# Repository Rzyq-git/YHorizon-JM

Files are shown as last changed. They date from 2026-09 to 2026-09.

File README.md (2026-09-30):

# YHorizon-JM

[中文](README.md) | [English](README.en.md)

开源关节电机。喜欢就请点个Star吧，当前仓库里的固件、SDK 和工具面向第一版样机：Classic CAN、GD32F303 驱动板。

> **本项目仅供交流学习。**
> 机械、电控、固件和 SDK 的源文件已全部公开。
> 不保证功能可靠、不保证使用安全，也不构成任何产品认证或质量承诺。
> **禁止他人将本仓库中的设计、固件、SDK 或文档用于商业用途。**
> 使用本项目造成的人身伤害、设备损坏或其它损失，由使用者自行承担。详见 [SECURITY.md](SECURITY.md)。

<p align="center">
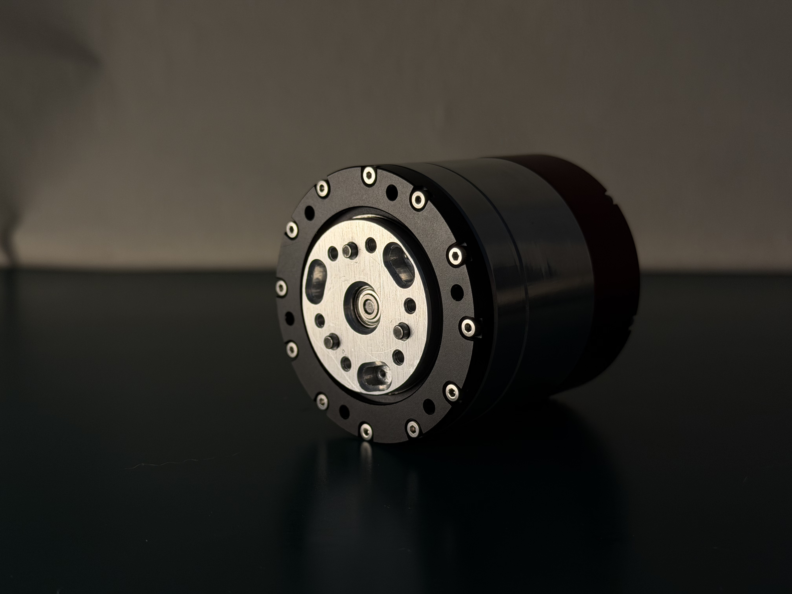
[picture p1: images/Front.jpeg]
输出法兰 / 正面
  
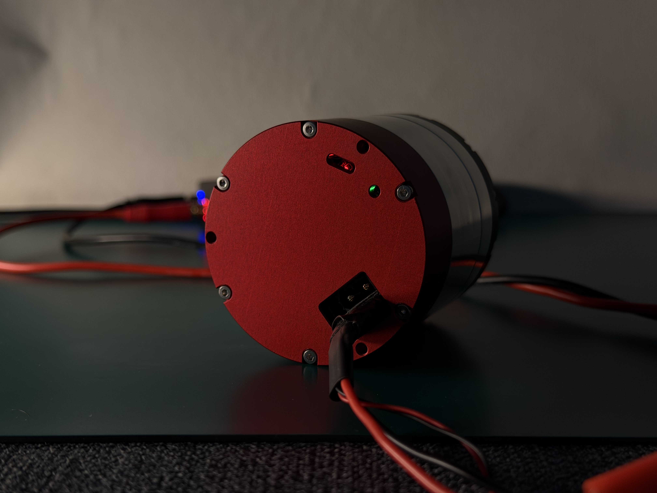
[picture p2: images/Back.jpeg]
后端盖 / 接线
  
</p>
<p align="center">
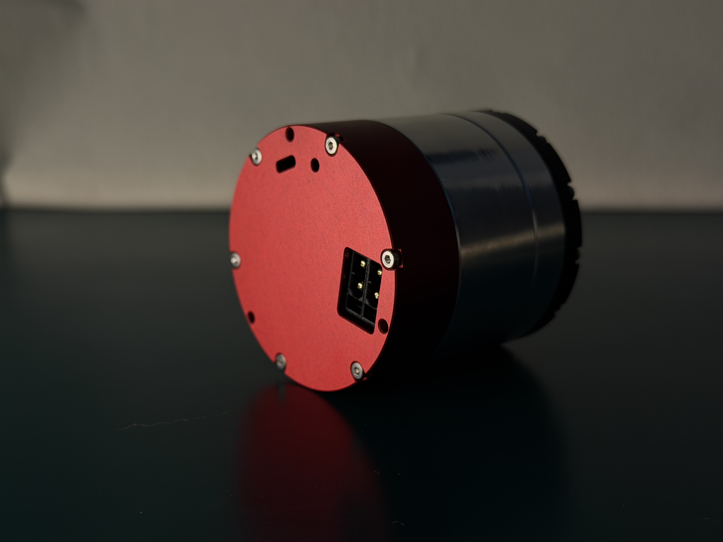
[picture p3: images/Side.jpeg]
侧面
  
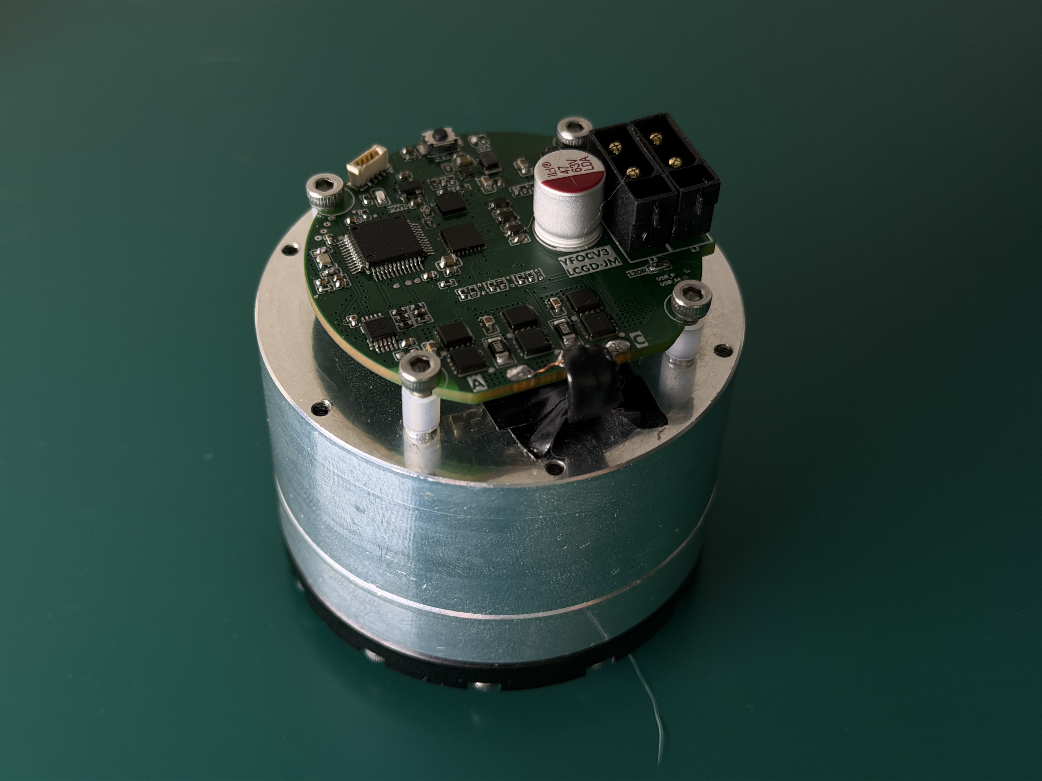
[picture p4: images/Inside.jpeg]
内部驱动板
  
</p>

<p align="center">
  正面（输出法兰）· 背面（电源与指示灯）· 侧面 · 内部驱动板
</p>

<p align="center">
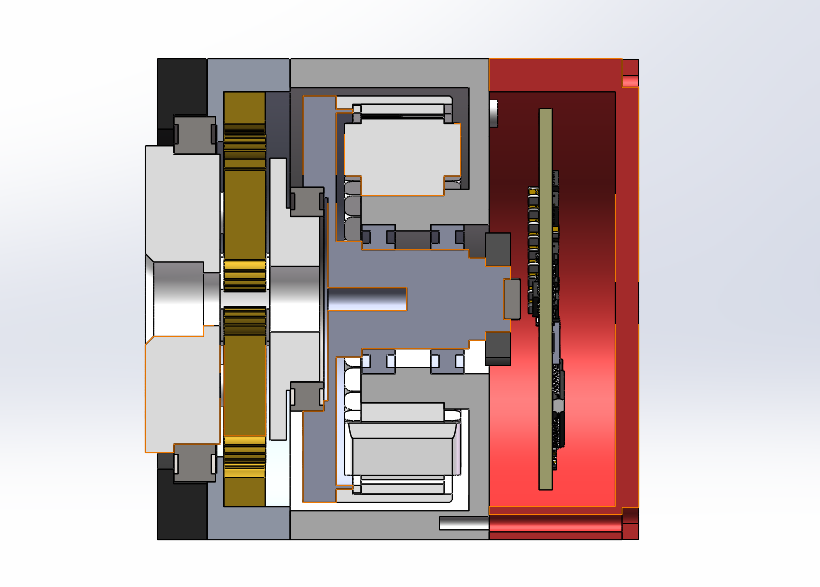
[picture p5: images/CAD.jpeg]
机械 CAD
  
</p>
<p align="center">
  机械结构（CAD）
</p>

## 当前电机

一体化关节，行星减速。第一版机械与电控：

| 项目 | 现状 |
| --- | --- |
| 外形 | 直径 57 mm，厚度 52 mm |
| 重量 | 约 300 g |
| 电机 | WK4310 参数，14 对极 |
| 减速 | 行星减速机，减速比 8 |
| 扭矩 | 额定 3 Nm，最大 6 Nm |
| 供电 | 最高 48 V |
| 编码器 | 双 MT6701 游标（30/31 齿），合成电机轴多圈后再除以减速比得到输出轴 |
| MCU | GD32F303CCT6，112 MHz |
| 功率级 | FD6288 三相驱动 |
| 总线 | Classic CAN 2.0，1 Mbps，Motor Protocol V1.0 |
| 控制 | 默认电压内环；可选电流内环。运控 / 速度 / 位置三模式 |

上电校准或加载 Flash 参数后进入运控。协议说明见 [`sdk/protocol/Motor CAN Protocol V1.0.md`](sdk/protocol/Motor%20CAN%20Protocol%20V1.0.md)（[English](sdk/protocol/Motor%20CAN%20Protocol%20V1.0.en.md)）。

测试视频：[自研关节电机阶段一完成｜D57 H52，8 倍减速，3Nm 稳定输出](https://www.bilibili.com/video/BV1CEtB6QELB/)

后续计划把主控换成 **GD32C113**，以支持 **CAN FD** 和多轴同步。机械接口与减速方案会尽量保持兼容，电控和协议会随 CAN FD 升级。

## 复刻

先对照两份清单备料、打板，不要直接下单目录里的其它文件：

- 机械零件与外购件：[`mechanical/bom/组装购买清单.xlsx`](mechanical/bom/组装购买清单.xlsx)
- 驱动器元器件：[`hardware/bom/BOM_YHorizon-JM.xlsx`](hardware/bom/BOM_YHorizon-JM.xlsx)

PCB 源工程（嘉立创 EDA Pro / EasyEDA Pro）：[`hardware/easyeda/ProPrj_YHorizon-JM.epro2`](hardware/easyeda/ProPrj_YHorizon-JM.epro2)。打板也可用 [`hardware/fabrication/Gerber_YHorizon-JM.zip`](hardware/fabrication/Gerber_YHorizon-JM.zip)，原理图 PDF 见 [`hardware/schematic/SCH_YHorizon-JM.pdf`](hardware/schematic/SCH_YHorizon-JM.pdf)。交流可加 QQ 群 **1124721315**。

装配体 STEP：[`mechanical/asm/YHorizon-JM-asm.STEP`](mechanical/asm/YHorizon-JM-asm.STEP)。CNC 零件在 `mechanical/cnc/`。**CNC 加工不保证和我们完全一致，建议多试、按自己的加工结果修改孔位。** 下单前请对照螺纹孔注意事项：

<p align="center">
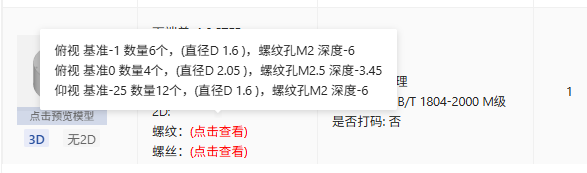
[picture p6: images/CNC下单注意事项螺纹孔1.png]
CNC 下单注意事项：螺纹孔 1
  
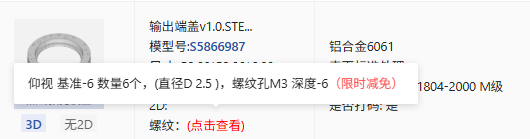
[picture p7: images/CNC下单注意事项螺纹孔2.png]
CNC 下单注意事项：螺纹孔 2
  
</p>
<p align="center">
  CNC 下单注意事项：螺纹孔 3
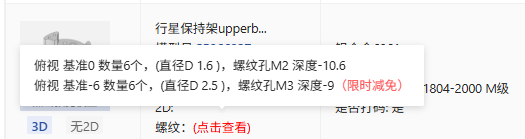
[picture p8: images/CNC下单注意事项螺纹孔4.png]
CNC 下单注意事项：螺纹孔 4
  
</p>
<p align="center">
  CNC 下单注意事项（螺纹孔）
</p>

也可以买一份我们整理的多余零部件套件，省去自己打板和配齿轮、螺丝：成品驱动板、减速机齿轮和部分螺丝等。预售在闲鱼（口令 **CZ225**）：[套件链接](https://m.tb.cn/h.8FFGGjp?tk=cgNcTkelna0)。

清单之外需要自己准备的工具（不限于）：

- 压力机
- 乐泰（Loctite）螺纹胶 / 固持胶
- 内六角扳手、小十字螺丝刀
- 烧录器线：0.8 mm 刺破式端子线

装配过程请看下面的视频：

- 测试：[自研关节电机阶段一完成｜D57 H52，8 倍减速，3Nm 稳定输出](https://www.bilibili.com/video/BV1CEtB6QELB/)
- 总装：[抖音装配视频](https://v.douyin.com/Lvc5RXRxO6M/)

复刻仅供交流学习，禁止商用。装配和上电前请阅读 [SECURITY.md](SECURITY.md)。

## 仓库结构

| 目录 | 内容 |
| --- | --- |
| `mechanical/asm/` | 装配体 STEP |
| `mechanical/cnc/` | CNC 模型 |
| `mechanical/gears/` | 齿轮 |
| `mechanical/bom/` | 零件 BOM |
| `hardware/easyeda/` | 嘉立创 EDA Pro 源工程 |
| `hardware/schematic/` | 原理图 |
| `hardware/fabrication/` | 制板文件 |
| `hardware/bom/` | 元器件 BOM |
| `firmware/` | GD32F303 固件 |
| `sdk/python/` | 上位机 Python SDK / GUI |
| `sdk/protocol/` | CAN 协议 |
| `tools/` | 环境、编译、烧录脚本 |
| `images/` | 样机照片、CAD 与 CNC 下单注意事项 |

## 固件

需要 `arm-none-eabi-gcc` 与 CMake + Ninja。产物：`firmware/build/gd32f303/YHorizon-JM.elf`。CLion 打开 `firmware/`，选择 preset `gd32f303`。

Windows：

```powershell
.\tools\setup-env.ps1
.\tools\build.ps1
.\tools\flash.ps1
```

Ubuntu：

```bash
./tools/setup-env.sh
./tools/build.sh
./tools/flash.sh
./tools/run-gui.sh
```

`setup-env.sh` 缺什么就用 apt 装什么，并创建 `sdk/python/.venv`。烧录探针为 CMSIS-DAP + SWD。发行版 OpenOCD 一般没有 `gd32f30x` 驱动，脚本会改用 `tools/openocd-gd32f303-stm32f1x.cfg`（按 256 KB，且不做 `mass_erase`）。

## 上位机

Ubuntu 跑完 `./tools/setup-env.sh` 后可直接 `./tools/run-gui.sh`。也可手动：

```bash
cd sdk/python
python3 -m venv .venv
source .venv/bin/activate   # Windows: .venv\Scripts\Activate.ps1
pip install -r requirements.txt
python servo_gui.py
```

CLI 示例：`python servo_host.py --interface socketcan --channel can0 --id 1 --listen`。协议说明见 `sdk/protocol/`。

## 许可证

采用双重许可证，详见 [`LICENSE`](LICENSE)。**源文件已全部公开；无论选用哪套许可证，本项目均仅供交流学习，禁止他人商用。**

| 内容 | 许可证 | 要点 |
| --- | --- | --- |
| `mechanical/`、`hardware/` | [CC BY-NC-SA 4.0](LICENSES/CC-BY-NC-SA-4.0.txt) | 禁止商用；衍生作品需同样开源并署名 |
| `firmware/`、`sdk/`、`tools/` | [GPLv3](LICENSES/GPL-3.0.txt) | 可学习、修改和分发；衍生软件必须继续按 GPLv3 开源 |

## 安全

完整免责声明见 [SECURITY.md](SECURITY.md)。关节电机能输出较大力矩；未完成限位、过流和急停验证前，不要在人体附近满功率运行。

## 贡献

见 [CONTRIBUTING.md](CONTRIBUTING.md)。

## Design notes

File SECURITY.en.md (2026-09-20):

# Disclaimer and safety

[中文](SECURITY.md) | [English](SECURITY.en.md)

Mechanical designs, electronics, firmware, SDK, tools, and documentation in this repository (the "Project") are provided for study and technical exchange only. Publishing this material does not mean the authors or contributors offer a product, support, training, or any warranty.

## Disclaimer

- The Project is provided "as is". It is not warranted for any particular purpose, continuous operation, freedom from defects, or compliance with functional safety, electrical safety, or other regulations.
- A joint motor can produce enough torque in a short time to crush a hand, throw a fixture, or damage a gearbox. Wrong wiring, wrong parameters, missing calibration, or failed protection can cause personal injury and property damage.
- Anyone who machines, assembles, flashes, tests, modifies, or integrates the Project does so at their own risk. Authors and contributors are not liable for direct, indirect, incidental, or consequential damages, including but not limited to personal injury, equipment damage, data loss, downtime, and commercial loss.
- The Project is not a certified industrial product. Before using it in a humanoid, cobot, near-person setting, vehicle, or any system that could cause harm, the user must complete their own risk assessment, testing, and safety measures.
- **Commercial use of the Project is prohibited.** Production, sale, paid integration, or other use for profit is outside the authors' authorization. Study, experiment, and open-source collaboration are the intended uses.

Using, copying, modifying, or distributing the Project means you have read and accepted these terms. Full licenses: [`LICENSE`](LICENSE).

## Before use

- Confirm mechanical limits, coupling/flange screws, and cable strain relief.
- Provide a hardware e-stop. Do not rely on a software stop alone.
- Jog first at low bus voltage and low current limits.
- Do not enable the position loop or high-gain impedance/force control before encoder calibration.
- Do not run at full power until current, temperature, and position limits have been verified.

## During operation

- Keep people, cables, and fixtures outside the output-flange envelope.
- Watch driver temperature, bus voltage, and fault codes.
- Power off immediately on runaway, abnormal noise, encoder jumps, or signs of over-current.
- Do not connect an uncalibrated torque loop to a humanoid or cobot load.

## Reporting safety issues

Treat firmware bugs, hardware design errors, and protection failures as safety issues. Do not post reproduction steps in a public Issue if they can directly cause over-current, runaway, or uncontrolled torque.

Report privately to maintainers when possible, including:

- Affected module (mechanical / hardware / firmware / SDK)
- Symptom and potential harm
- Software or hardware version
- Mitigations already applied

Maintainers may fix the issue or add documentation. That does not change this disclaimer: the Project still does not promise timely fixes and does not accept liability for use.

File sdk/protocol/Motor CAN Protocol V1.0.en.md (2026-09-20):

# Motor CAN Protocol V1.0

[中文](Motor%20CAN%20Protocol%20V1.0.md) | [English](Motor%20CAN%20Protocol%20V1.0.en.md)

Protocol actually implemented by current YHorizon-JM firmware. Classic CAN 2.0, 11-bit ID, DLC = 8, 1 Mbps, little-endian. Motor ID = 1~63. Position and velocity are on the **output shaft** (motor shaft / gear ratio 8).

After power-on calibration or a successful Flash load the drive enters `RUNNING`. There is no `ENABLE` / `DISABLE`. Voltage inner loop by default; `CFG_INNER_LOOP` in `config.h` can select current inner loop. CAN still encodes `t_ref` in voltage units.

## CAN IDs

| CAN ID | Direction | Function |
| --- | --- | --- |
| `0x100 + ID` | Host → motor | Motion command |
| `0x140 + ID` | Host → motor | Velocity command |
| `0x180 + ID` | Host → motor | SET gains |
| `0x180 + ID` | Motor → host | GET gains reply |
| `0x1C0 + ID` | Host → motor | Position command |
| `0x200 + ID` | Host → motor | Management |
| `0x280 + ID` | Motor → host | Command ACK |
| `0x300 + ID` | Motor → host | Motion feedback |
| `0x380 + ID` | Motor → host | GET_STATUS reply |
| `0x3C0 + ID` | Motor → host | Calibration progress |

## Control mode and state

```text
Control Mode    0x00 MOTION    0x01 VELOCITY    0x02 POSITION
Motor State     0x02 RUNNING   0x03 FAULT       0x04 CALIBRATING
```

Power-on default is `MOTION`. `SET_CONTROL_MODE` may switch while `RUNNING`; integrators are cleared and voltage is 0 until a valid real-time command for the new mode arrives. The drive executes only real-time frames that match the current mode; others are dropped with no feedback.

If several real-time frames arrive in one RX pass, only the last valid one is applied. There is no timeout: the last frame is held until a new command of the same mode, a mode change, calibration, FAULT, or power-off. To stop, send zero speed / current position, or power down.

Calibration blocks the main loop for several seconds. Other commands are not handled during that time; queued motion frames are discarded afterward.

## Real-time commands

Call `SET_CONTROL_MODE` first, then send matching real-time frames. A valid frame is answered with `0x300` and no extra ACK.

### Motion `0x100 + ID`

| Byte | Field | Type | Encoding |
| --- | --- | --- | --- |
| 0~3 | Position command | `int32` | `0.0001 rad/LSB` |
| 4~5 | Velocity command | `int16` | `0.1 rad/s/LSB`; values beyond about `±3276.7` are clamped, then still executed |
| 6~7 | Voltage FF | `int16` | `raw / 32767` → −1~1 |

```text
t_ref = Kd*(v_set - v_act) + Kp*(p_set - p_act) + Voltage_ff
t_ref = clamp(t_ref, ±V_LIMIT)
```

`V_LIMIT` defaults to 0.50 pu (1.0 = full PWM).

### Velocity `0x140 + ID`

| Byte | Field | Type | Encoding |
| --- | --- | --- | --- |
| 0~3 | Velocity command | `int32` | `0.1 rad/s/LSB` |
| 4~7 | Reserved | | Must be 0, otherwise the frame is dropped |

```text
u = Kp*e_v + Ki*∫e_v dt     integral clamped to ±V_LIMIT
```

### Position `0x1C0 + ID`

| Byte | Field | Type | Encoding |
| --- | --- | --- | --- |
| 0~3 | Position command | `int32` | `0.0001 rad/LSB` |
| 4~7 | Maximum velocity | `uint32` | `0.1 rad/s/LSB`, absolute limit |

A position PID outer loop builds `v_ref` (clamped to `±vmax`), then the velocity PI inner loop runs with the VELOCITY gain set. Outer-loop integration freezes while the inner loop is saturated.

### Motion feedback `0x300 + ID`

| Byte | Field | Type | Encoding |
| --- | --- | --- | --- |
| 0~3 | Position | `int32` | `0.0001 rad/LSB`, continuous multi-turn |
| 4~5 | Velocity | `int16` | `0.1 rad/s/LSB` |
| 6~7 | Voltage command | `int16` | `0.001 pu/LSB` (protocol torque field; no torque sensor) |

Reported only after a valid real-time command.

## Gains `0x180 + ID`

SET: host → motor. Successful GET: motor → host, same layout.

| Byte | Field |
| --- | --- |
| 0 | Control Mode |
| 1 | Sequence |
| 2~3 | Kp `uint16` |
| 4~5 | Ki `uint16` |
| 6~7 | Kd `uint16` |

| Mode | Kp | Ki | Kd |
| --- | --- | --- | --- |
| MOTION | `0.01 pu/rad` | Must be 0 | `0.001 pu·s/rad` |
| VELOCITY | `0.001 pu/(rad/s)` | `0.001 pu/rad` | Must be 0 |
| POSITION | `0.01 s⁻¹` | `0.001 s⁻²` | `0.001` |

SET updates RAM only. ACK is on `0x280` (Command=`0x20`). Illegal mode, or a gain that must be 0 is not 0 → `PARAMETER_OUT_OF_RANGE`, previous parameters kept. Motion gains are not stored across power cycles; velocity/position gains are written to Flash with `SAVE_USER_PARAMS`.

GET_GAINS (`0x200`, Byte0=`0x21`, Byte2=mode, rest 0): success returns current RAM on `0x180` with no extra ACK; failure returns an error on `0x280`.

## Management `0x200 + ID`

| Byte | Field |
| --- | --- |
| 0 | Command |
| 1 | Sequence |
| 2~7 | Parameters; unused bytes must be 0 |

| Command | Value | Notes |
| --- | --- | --- |
| SET_ZERO | `0x03` | Zero the current output shaft and write Flash |
| CLEAR_FAULT | `0x04` | Clears `CALIBRATION_FAULT` only. Afterward State=`RUNNING` but PWM is off; calibrate again before motion |
| START_ENCODER_CALIBRATION | `0x05` | Allowed in `RUNNING`; ACK first, then calibrate |
| SET_CONTROL_MODE | `0x06` | Byte2 = mode. `FAULT` → `INVALID_STATE` |
| SET_NODE_ID | `0x07` | Byte2 = new ID (1~63). ACK on the old ID (Byte6=new ID), then reset after about 20 ms |
| SAVE_USER_PARAMS | `0x08` | Write velocity Kp/Ki and position Kp/Ki/Kd to the same Flash page as calibration |
| GET_STATUS | `0x10` | Reply on `0x380`, no extra ACK |
| GET_GAINS | `0x21` | See previous section |

Unknown commands (including `ENABLE 0x01` / `DISABLE 0x02`) return `INVALID_COMMAND`. A repeat of the same Command+Sequence returns the cached reply and is not executed again.

### Command ACK `0x280 + ID`

| Byte | Field |
| --- | --- |
| 0 | Command |
| 1 | Sequence |
| 2 | Result |
| 3 | Motor State |
| 4~5 | Fault Code |
| 6 | New ID after a successful SET_NODE_ID, otherwise 0 |
| 7 | 0 |

```text
Result  0x00 OK
        0x01 INVALID_COMMAND
        0x02 INVALID_STATE
        0x03 PARAMETER_OUT_OF_RANGE
        0x04 FAULT_ACTIVE
        0x05 BUSY            // start/SAVE while calibrating
        0x06 INTERNAL_ERROR  // Flash write failed
```

### GET_STATUS reply `0x380 + ID`

| Byte | Field |
| --- | --- |
| 0 | Motor State |
| 1~2 | Fault Code `uint16` |
| 3~4 | Bus voltage `uint16`, `0.01 V/LSB` (measured on PB0) |
| 5~6 | Temperature, currently 0 |
| 7 | bits 5~6 = Control Mode; warning bits are 0 |

Only fault bit `bit10 CALIBRATION_FAULT` is used. No unsolicited Fault Event; status is returned only for `GET_STATUS`.

## Encoder calibration `0x3C0 + ID`

`START_ENCODER_CALIBRATION` ACKs first (State=`CALIBRATING`), then runs blocked. A report is sent about every 50 ms, plus immediately on Stage change. Success returns to `RUNNING`; failure goes to `FAULT` + `CALIBRATION_FAULT`. Power-on with invalid NV uses the same path and reports with Sequence=0 and no Command ACK.

| Byte | Field |
| --- | --- |
| 0 | Sequence |
| 1 | State: `0x01 RUNNING` / `0x02 SUCCESS` / `0x03 FAILED` |
| 2 | Progress 0~100 |
| 3 | Stage |
| 4~5 | Error Code |
| 6~7 | 0 |

```text
Stage   0x01 PRE_CHECK
        0x02 MOTOR_ALIGNMENT
        0x03 ENCODER_SAMPLING
        0x04 PARAMETER_CALCULATION
        0x05 PARAMETER_SAVE
        0x06 COMPLETE

Error   0x0000 NO_ERROR
        0x0002 ENCODER_SIGNAL_ERROR
        0x0004 CALIBRATION_DATA_INVALID
        0x0005 PARAMETER_SAVE_FAILED
```

CAN is paused briefly while writing Flash, so reports may skip during `PARAMETER_SAVE`.

## Suggested sequence

```text
Power on → wait until calibration finishes or GET_STATUS is RUNNING
SET_CONTROL_MODE
SET_GAINS (for that mode)
Stream matching real-time commands, receive 0x300
SAVE_USER_PARAMS / SET_ZERO / SET_NODE_ID as needed
```

ID can also be changed with the button: hold PB1 for 2 s to enter, short press to increment, hold again to save and reset. The LED blinks the ID (tens as long blinks, ones as short blinks).

## Later work

This is a single-axis Classic CAN 1 Mbps protocol. Planned next:

- **CAN FD** after moving the MCU to **GD32C113**
- Multi-axis sync (shared clock / sync frames, batched position or impedance)
- `ENABLE` / `DISABLE` and fuller fault detection (over-current, over-voltage, over-temperature, stall)
- Torque-unit feedback and unsolicited Fault Events

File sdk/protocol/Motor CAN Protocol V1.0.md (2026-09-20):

# Motor CAN Protocol V1.0

[中文](Motor%20CAN%20Protocol%20V1.0.md) | [English](Motor%20CAN%20Protocol%20V1.0.en.md)

YHorizon-JM 当前固件实际使用的协议。Classic CAN 2.0，11-bit ID，DLC = 8，1 Mbps，小端。Motor ID = 1~63。位置、速度均指**输出轴**（电机轴 / 减速比 8）。

上电校准或加载 Flash 成功后直接进入 `RUNNING`，没有 `ENABLE` / `DISABLE`。默认电压内环；`config.h` 的 `CFG_INNER_LOOP` 可改为电流内环，CAN 仍按电压量纲编码 `t_ref`。

## CAN ID

| CAN ID | 方向 | 功能 |
| --- | --- | --- |
| `0x100 + ID` | 主机 → 电机 | Motion Command |
| `0x140 + ID` | 主机 → 电机 | Velocity Command |
| `0x180 + ID` | 主机 → 电机 | SET Gains |
| `0x180 + ID` | 电机 → 主机 | GET Gains 应答 |
| `0x1C0 + ID` | 主机 → 电机 | Position Command |
| `0x200 + ID` | 主机 → 电机 | 管理命令 |
| `0x280 + ID` | 电机 → 主机 | Command ACK |
| `0x300 + ID` | 电机 → 主机 | Motion Feedback |
| `0x380 + ID` | 电机 → 主机 | GET_STATUS 应答 |
| `0x3C0 + ID` | 电机 → 主机 | 校准进度 |

## 控制模式与状态

```text
Control Mode    0x00 MOTION    0x01 VELOCITY    0x02 POSITION
Motor State     0x02 RUNNING   0x03 FAULT       0x04 CALIBRATING
```

上电默认 `MOTION`。`SET_CONTROL_MODE` 在 `RUNNING` 下切换；切换后清积分，电压为 0，直到收到新模式的有效实时命令。驱动器只执行与当前模式匹配的实时帧，其它实时帧丢弃且不回 Feedback。

同一轮 RX 若有多帧实时命令，只执行最后一帧有效命令。无超时：保持最后一帧，直到同模式新命令、切模式、校准、FAULT 或掉电。停止运动请发零速度/当前位置，或断电。

校准会阻塞主循环数秒；期间不处理其它命令，结束后丢弃积压的运控帧。

## 实时命令

先 `SET_CONTROL_MODE`，再发对应实时帧。有效帧后回 `0x300`，无额外 ACK。

### Motion `0x100 + ID`

| Byte | 数据 | 类型 | 编码 |
| --- | --- | --- | --- |
| 0~3 | 目标位置 | `int32` | `0.0001 rad/LSB` |
| 4~5 | 目标速度 | `int16` | `0.1 rad/s/LSB`，超出约 `±3276.7` 则钳位后仍执行 |
| 6~7 | Voltage FF | `int16` | `raw / 32767` → −1~1 |

```text
t_ref = Kd*(v_set - v_act) + Kp*(p_set - p_act) + Voltage_ff
t_ref = clamp(t_ref, ±V_LIMIT)
```

`V_LIMIT` 默认 0.50 pu（1.0 = PWM 满幅）。

### Velocity `0x140 + ID`

| Byte | 数据 | 类型 | 编码 |
| --- | --- | --- | --- |
| 0~3 | 目标速度 | `int32` | `0.1 rad/s/LSB` |
| 4~7 | Reserved | | 必须为 0，否则丢弃 |

```text
u = Kp*e_v + Ki*∫e_v dt     积分钳位到 ±V_LIMIT
```

### Position `0x1C0 + ID`

| Byte | 数据 | 类型 | 编码 |
| --- | --- | --- | --- |
| 0~3 | 目标位置 | `int32` | `0.0001 rad/LSB` |
| 4~7 | 最大速度 | `uint32` | `0.1 rad/s/LSB`，绝对值上限 |

位置 PID 外环生成 `v_ref`（限幅 `±vmax`），再走速度 PI 内环（使用 VELOCITY 那组增益）。内环饱和时冻结外环积分。

### Motion Feedback `0x300 + ID`

| Byte | 数据 | 类型 | 编码 |
| --- | --- | --- | --- |
| 0~3 | 当前位置 | `int32` | `0.0001 rad/LSB`，连续多圈 |
| 4~5 | 当前速度 | `int16` | `0.1 rad/s/LSB` |
| 6~7 | 电压指令 | `int16` | `0.001 pu/LSB`（协议 Torque 字段；无转矩传感器） |

只在有效实时命令之后上报。

## 增益 `0x180 + ID`

SET：主机 → 电机。GET 成功：电机 → 主机，布局相同。

| Byte | 内容 |
| --- | --- |
| 0 | Control Mode |
| 1 | Sequence |
| 2~3 | Kp `uint16` |
| 4~5 | Ki `uint16` |
| 6~7 | Kd `uint16` |

| 模式 | Kp | Ki | Kd |
| --- | --- | --- | --- |
| MOTION | `0.01 pu/rad` | 必须为 0 | `0.001 pu·s/rad` |
| VELOCITY | `0.001 pu/(rad/s)` | `0.001 pu/rad` | 必须为 0 |
| POSITION | `0.01 s⁻¹` | `0.001 s⁻²` | `0.001` |

SET 只改 RAM，ACK 在 `0x280`（Command=`0x20`）。Mode 非法或应为 0 的增益非 0 → `PARAMETER_OUT_OF_RANGE`，原参数不变。Motion 增益不上电保存；速度/位置增益用 `SAVE_USER_PARAMS` 写入 Flash。

GET_GAINS（`0x200`，Byte0=`0x21`，Byte2=mode，其余 0）：成功在 `0x180` 回当前 RAM，无额外 ACK；失败在 `0x280` 回错误。

## 管理命令 `0x200 + ID`

| Byte | 内容 |
| --- | --- |
| 0 | Command |
| 1 | Sequence |
| 2~7 | 参数，未用字节必须为 0 |

| Command | 值 | 说明 |
| --- | --- | --- |
| SET_ZERO | `0x03` | 当前输出轴置零并写 Flash |
| CLEAR_FAULT | `0x04` | 仅清除 `CALIBRATION_FAULT`。清除后 State=`RUNNING`，PWM 关闭，需再校准才接受运控 |
| START_ENCODER_CALIBRATION | `0x05` | `RUNNING` 下可启动；先 ACK 再校准 |
| SET_CONTROL_MODE | `0x06` | Byte2 = 模式。`FAULT` → `INVALID_STATE` |
| SET_NODE_ID | `0x07` | Byte2 = 新 ID（1~63）。旧 ID 回 ACK（Byte6=新 ID）后约 20 ms 复位 |
| SAVE_USER_PARAMS | `0x08` | 把速度 Kp/Ki 与位置 Kp/Ki/Kd 写入校准同一 Flash 页 |
| GET_STATUS | `0x10` | 应答在 `0x380`，无额外 ACK |
| GET_GAINS | `0x21` | 见上一节 |

未知命令（含 `ENABLE 0x01` / `DISABLE 0x02`）回 `INVALID_COMMAND`。相同 Command+Sequence 重发返回缓存应答，不重复执行。

### Command ACK `0x280 + ID`

| Byte | 内容 |
| --- | --- |
| 0 | Command |
| 1 | Sequence |
| 2 | Result |
| 3 | Motor State |
| 4~5 | Fault Code |
| 6 | SET_NODE_ID 成功时为新 ID，其它为 0 |
| 7 | 0 |

```text
Result  0x00 OK
        0x01 INVALID_COMMAND
        0x02 INVALID_STATE
        0x03 PARAMETER_OUT_OF_RANGE
        0x04 FAULT_ACTIVE
        0x05 BUSY          // 校准中再发启动/SAVE
        0x06 INTERNAL_ERROR  // 写 Flash 失败
```

### GET_STATUS 应答 `0x380 + ID`

| Byte | 内容 |
| --- | --- |
| 0 | Motor State |
| 1~2 | Fault Code `uint16` |
| 3~4 | 母线电压 `uint16`，`0.01 V/LSB`（PB0 实测） |
| 5~6 | 温度，当前填 0 |
| 7 | bit5~6 = Control Mode，Warning 位填 0 |

当前仅使用故障位 `bit10 CALIBRATION_FAULT`。不主动发 Fault Event，只响应 `GET_STATUS`。

## 编码器校准 `0x3C0 + ID`

`START_ENCODER_CALIBRATION` 先 ACK（State=`CALIBRATING`），再阻塞执行。约 50 ms 上报一帧，Stage 变化立即多发一帧。成功后回 `RUNNING`；失败进入 `FAULT` + `CALIBRATION_FAULT`。上电无有效 NV 时走同一套流程并上报，Sequence=0，没有 Command ACK。

| Byte | 内容 |
| --- | --- |
| 0 | Sequence |
| 1 | State：`0x01 RUNNING` / `0x02 SUCCESS` / `0x03 FAILED` |
| 2 | Progress 0~100 |
| 3 | Stage |
| 4~5 | Error Code |
| 6~7 | 0 |

```text
Stage   0x01 PRE_CHECK
        0x02 MOTOR_ALIGNMENT
        0x03 ENCODER_SAMPLING
        0x04 PARAMETER_CALCULATION
        0x05 PARAMETER_SAVE
        0x06 COMPLETE

Error   0x0000 NO_ERROR
        0x0002 ENCODER_SIGNAL_ERROR
        0x0004 CALIBRATION_DATA_INVALID
        0x0005 PARAMETER_SAVE_FAILED
```

写 Flash 时短暂停 CAN，`PARAMETER_SAVE` 阶段上报可能有缺口。

## 推荐流程

```text
上电 → 等校准结束或 GET_STATUS 为 RUNNING
SET_CONTROL_MODE
SET_GAINS（按模式）
周期发送对应实时命令，收 0x300
需要时 SAVE_USER_PARAMS / SET_ZERO / SET_NODE_ID
```

也可用按键改 ID：PB1 长按 2 s 进入，短按 +1，再长按保存并复位。LED 按 ID 闪烁（十位长闪 + 个位短闪）。

## 后续计划

当前为 Classic CAN 1 Mbps 的单轴协议。后续准备：

- 主控换到 **GD32C113** 后支持 **CAN FD**
- 多轴同步（共享时钟/同步帧，批量下发位置或阻抗）
- `ENABLE` / `DISABLE` 与更完整的故障检测（过流、过压、过温、堵转）
- 转矩量纲反馈与主动 Fault Event

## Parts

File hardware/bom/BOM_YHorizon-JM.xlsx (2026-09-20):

No. | Quantity | Comment | Designator | Footprint | Value | Manufacturer | Voltage Rated | Voltage - Supply | Overload Voltage (Max) | Device | Name | Symbol
1 | 17 | 100nF | C1,C3,C4,C5,C7,C9,C14,C19,C20,C36,C37,C38,C39,C40,C41,C43,C44 | C0402 | 100nF | SAMSUNG(三星) | 50V |  |  | C 0402-100nF,CL05B104KB54PNC,CL05B104KO5NNNC | 100nF | C 0402,CL05B104KB54PNC,CL05B104KO5NNNC
2 | 3 | 10uF | C2,C8,C11 | C0603 | 10uF | Chinocera(华瓷),SAMSUNG(三星) |  |  |  | CL10A106MA8NRNC,HGC0603R5106M160NTHJ | 10uF | CL10A106MA8NRNC,HGC0603R5106M160NTHJ
3 | 1 | 10nF | C6 | C0402 | 10nF | SAMSUNG(三星) |  |  |  | CL05B103KB5NNNC | 10nF | CL05B103KB5NNNC
4 | 4 | 1uF | C10,C17,C18,C42 | C0402 | 1uF | SAMSUNG(三星) |  |  |  | CL05A105KA5NQNC | 1uF | CL05A105KA5NQNC
5 | 2 | 33pF | C12,C15 | C0402 | 33pF | YAGEO(国巨) | 50V |  |  | CC0402JRNPO9BN330 | 33pF | CC0402JRNPO9BN330
6 | 1 | 22uF | C13 | C0603 | 22uF | SAMSUNG(三星) |  |  |  | CL10A226MP8NUNE | 22uF | CL10A226MP8NUNE
7 | 10 | 4.7uF | C16,C21,C22,C23,C24,C25,C26,C27,C28,C29 | C0805 | 4.7uF | HRE(芯声),SAMSUNG(三星) |  |  |  | CIA0805X5R475K101MT,CL21A475KBQNNNE | 4.7uF | CIA0805X5R475K101MT,CL21A475KBQNNNE
8 | 1 | 47uF | C30 | CAP-TH_BD8.0-P3.50-D0.6-FD | 47uF | JIERR(捷而瑞) |  |  |  | PA100V47M8X11 | 47uF | PA100V47M8X11
9 | 2 | 8pF | C31,C32 | C0402 | 8pF | FH(风华) |  |  |  | 0402CG8R0C500NT | 8pF | 0402CG8R0C500NT_C1578
10 | 3 | 100nF | C33,C34,C35 | C0603 | 100nF | SAMSUNG(三星) |  |  |  | CL10B104KC8NNNC | 100nF | CL10B104KC8NNNC
11 | 2 | 100nF | C45,C46 | C0201 | 100nF | muRata(村田) |  |  |  | GRM033R61E104KE14D | 100nF | GRM033R61E104KE14D
12 | 2 | XT30(2+2)PB-M.G.B | CN1,CN2 | CONN-TH_XT30PB-M |  | AMASS(艾迈斯) |  |  |  | XT30(2+2)PB-M.G.B | XT30(2+2)PB-M.G.B | XT30(2+2)PB-M.G.B
13 | 1 | WAFER-0.8-4PLB | CN3 | CONN-SMD_4P-P0.80_XUNPU_WAFER-0.8-4PLB |  | XUNPU(讯普) |  |  |  | WAFER-0.8-4PLB | WAFER-0.8-4PLB | WAFER-0.8-4PLB
14 | 1 | SMF48A | D1 | SOD-123FL_L2.8-W1.8-LS3.8-RD |  | R+O(宏嘉诚) |  |  |  | SMF48A_C42371754 | SMF48A | SMF48A_C42371754
15 | 3 | B5819WS | D2,D3,D4 | SOD-323_L1.7-W1.3-LS2.5-FD |  | R+O(宏嘉诚) |  |  |  | B5819WS_C7420331 | B5819WS | B5819WS_C7420331
16 | 3 | BAT41KFILM | D5,D6,D7 | SOD-523_L1.2-W0.8-LS1.6-RD |  | ST(意法半导体) |  |  |  | BAT41KFILM | BAT41KFILM | BAT41KFILM
17 | 1 | 22uH | L1 | IND-SMD_L2.5-W2.0_MHCHL2520 | 22uH | cjiang(长江微电) |  |  |  | FTC252010S220MBCA | 22uH | FTC252010S220MBCA
18 | 1 | GL0603UR01 | LED1 | LED0603-FD |  | Guiguang light(桂光光电) |  |  |  | GL0603UR01 | GL0603UR01 | GL0603UR01
19 | 1 | NCD0402G1 | LED2 | LED-SMD_L1.0-W0.5_FC-F1005UGK |  | 国星光电 |  |  |  | NCD0402G1 | NCD0402G1 | FC-F1005UGK-520M5
20 | 6 | HSBB6066 | Q1,Q2,Q3,Q4,Q5,Q6 | PDFN3333-8_L3.1-W3.2-P0.65-LS3.4-BL_1 |  | HUASHUO(华朔) |  |  |  | HSBB6066 | HSBB6066 | HSBB6066
21 | 2 | 100kΩ | R1,R10 | R0402 | 100kΩ | UNI-ROYAL(厚声) |  |  | 50V | 0402WGF1003TCE,R0402-100K | 100kΩ | 0402WGF1003TCE,R0402
22 | 1 | 0Ω | R2 | R0402 | 0Ω | YAGEO(国巨) |  |  |  | RC0402FR-070RL | 0Ω | RC0402FR-070RL
23 | 1 | 3.3kΩ | R3 | R0402 | 3.3kΩ | UNI-ROYAL(厚声) |  |  |  | 0402WGF3301TCE | 3.3kΩ | 0402WGF3301TCE
24 | 1 | 47kΩ | R4 | R0402 | 47kΩ | UNI-ROYAL(厚声) |  |  |  | 0402WGF4702TCE | 47kΩ | 0402WGF4702TCE
25 | 4 | 5.1kΩ | R5,R6,R14,R25 | R0402 | 5.1kΩ | UNI-ROYAL(厚声) |  |  |  | 0402WGF5101TCE | 5.1kΩ | 0402WGF5101TCE
26 | 1 | 20kΩ | R7 | R0402 | 20kΩ | UNI-ROYAL(厚声) |  |  | 50V | 0402WGF2002TCE | 20kΩ | 0402WGF2002TCE
27 | 1 | 158kΩ | R8 | R0402 | 158kΩ | UNI-ROYAL(厚声) |  |  |  | 0402WGF1583TCE | 158kΩ | 0402WGF1583TCE
28 | 11 | 10kΩ | R9,R15,R16,R21,R22,R23,R24,R30,R31,R32,R35 | R0402 | 10kΩ | UNI-ROYAL(厚声),YAGEO(国巨) |  |  | 50V | R0402-10K,RC0402FR-0710KL,RT0402BRD0710KL | 10kΩ | R0402,RC0402FR-0710KL,RT0402BRD0710KL
29 | 1 | 30kΩ | R11 | R0402 | 30kΩ | UNI-ROYAL(厚声) |  |  |  | 0402WGJ0303TCE | 30kΩ | 0402WGJ0303TCE
30 | 1 | 147kΩ | R12 | R0402 | 147kΩ | UNI-ROYAL(厚声) |  |  | 50V | R0402-147K |  | R0402
31 | 1 | 33kΩ | R13 | R0402 | 33kΩ | FOJAN(富捷) |  |  |  | FRC0402F3302TS | 33kΩ | FRC0402F3302TS
32 | 6 | 2.2Ω | R17,R18,R19,R27,R28,R29 | R0402 | 2.2Ω | FOJAN(富捷) |  |  |  | FRC0402J2R2 TS | 2.2Ω | FRC0402J2R2 TS
33 | 1 | 120Ω | R20 | R0603 | 120Ω | UNI-ROYAL(厚声) |  |  | 75V | 0603WAF1200T5E | 120Ω | 0603WAF1200T5E
34 | 1 | SDNT1608X103F3950FTF | R26 | R0603 |  | Sunlord(顺络) |  |  |  | SDNT1608X103F3950FTF | SDNT1608X103F3950FTF | SDNT1608X103F3950FTF
35 | 2 | 1mΩ | R33,R34 | R1206 | 1mΩ | JIERR(捷而瑞) |  |  |  | RE1206F1R001 | 1mΩ | RE1206F1R001
36 | 1 | TS-1088-AR02016 | SW1 | SW-SMD_L3.9-W3.0-P4.45 |  | XUNPU(讯普) |  |  |  | TS-1088-AR02016 | TS-1088-AR02016 | TS-1088-AR02016
37 | 14 | Test-Point | TP1,TP2,TP3,TP4,TP5,TP6,TP7,TP8,TP9,TP10,TP11,TP12,TP13,TP14 | Test-Point-0.5mm |  |  |  |  |  | Test-Point |  | Test-Point
38 | 1 | TPS562242DRLR | U1 | SOT-5X3-6_W1.6-L1.2-P0.50-LS1.6-BL |  | TI(德州仪器) |  | 3V~17V |  | TPS562242DRLR | TPS562242DRLR | TPS562242DRLR
39 | 1 | FD6288Q | U2 | QFN-24_L4.0-W4.0-P0.50-BL-EP2.6 |  | Fortior Tech(峰岹) |  | 5V~20V |  | FD6288Q | FD6288Q | FD6288Q_C328453
40 | 1 | 3.3uH | U3 | IND-SMD_L2.5-W2.0 | 3.3uH | cjiang(长江微电) |  |  |  | FTC252012S3R3MBCA | 3.3uH | FTC252012S3R3MBCA
41 | 1 | LMR51610YFDBVR | U4 | SOT-23-6_L2.9-W1.6-P0.95-LS2.8-BL |  | TI(德州仪器) |  | 4V~65V |  | LMR51610YFDBVR | LMR51610YFDBVR | LMR51610YFDBVR
42 | 1 | TPS7A2433DBVR | U5 | SOT-23-5_L2.9-W1.6-P0.95-LS2.8-BR |  | TI(德州仪器) |  | 18V |  | TPS7A2433DBVR | TPS7A2433DBVR | TPS7A2433DBVR
43 | 1 | INA2181A1IDGSR | U6 | VSSOP-10_L3.0-W3.0-P0.50-LS4.9-BL |  | TI(德州仪器) |  |  |  | INA2181A1IDGSR | INA2181A1IDGSR | INA2181A1IDGSR
44 | 1 | SIT1051AQTK/3 | U7 | DFN-8_L3.0-W3.0-P0.65-BL-EP-1 |  | SIT(芯力特) |  | 4.5V~5.5V |  | SIT1051AQTK/3 | SIT1051AQTK/3 | SIT1051AQTK/3
45 | 2 | MT6701QT-STD | U8,U10 | QFN-16_L3.0-W3.0-P0.50-TL-EP1.7 |  | MagnTek(麦歌恩) |  |  |  | MT6701QT-STD | MT6701QT-STD | MT6701QT-STD_C2913974
46 | 1 | GD32F303CCT6 | U9 | LQFP-48_L7.0-W7.0-P0.50-LS9.0-BL |  | GigaDevice(兆易创新) |  | 2.6V~3.6V |  | GD32F303CCT6 | GD32F303CCT6 | GD32F303CCT6
47 | 1 | 32MHz | X1 | CRYSTAL-SMD_4P-L1.6-W1.2-BL | 32MHz | YXC(扬兴晶振) |  |  |  | XL4EL89CKI-111YLC-32M | 32MHz | XL4EL89CKI-111YLC-32M

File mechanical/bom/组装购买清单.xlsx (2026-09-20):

清单明细表（看着多但10分钟即可买完）
序号 | 产品名称 | 规格/单位 | 型号 | 数量 | 价格 | 备注
铨洲 | 行星保持架lower_base轴承公差版本.STEP | 6061 | 铨洲版本 | 1 | 6.8 | 价格因个人用券稍有浮动，大概250元能拿下。还有大家也可选择性进行打印，如果有打印机的后壳可以打印，其他的最好cnc，但最好改改孔位，防止热缩率带来的装配问题
 | 行星保持架upperbase4.0轴承公差版本.STEP | 6061 | 铨洲版本 | 1 | 32.8
 | 后壳.STEP | 6061 | 铨洲版本 | 1 | 26.8
 | 输出端盖v1.0.STEP | 6061 | 铨洲版本 | 1 | 6.8
 | 50-外齿圈支架v1.0.STEP | 6061 | 铨洲版本 | 1 | 6.8
 | 下端盖v1.0.STEP | 6061 | 铨洲版本 | 1 | 103.8
 | 电机输出盘v1.0.STEP | 6061 | 铨洲版本 | 1 | 68.8
YHorizon.套件 | 电机驱动板 | PCB | V1.0 | 1 | 268元（10.1日前预售价格）298元（10.1日后） | 配件啥的不值钱，为了方便大家减少购买链接，提升一次性成功率，不漏买，少买，买错，我们直接打包了，有可能出现多放几个，是因为主播懒得数了，一般不会少的。
 | 修型变位行星齿 | 45钢淬火 | V1.0 | 3
 | 修型变位太阳齿 | 45钢淬火 | V1.0 | 1
 | 修型变位内齿圈 | 45钢淬火 | V1.0 | 1
 | 中心磁编齿 | POM | V1.0 | 1
 | 旁置磁编齿 | POM | V1.0 | 1
 | M2前后端盖通用丝 | 赠与 | V1.0 | ≥18
 | 4*2.7*5PCB隔套 | 赠与 | V1.0 | ≥4
 | M2.5PCB固定丝 | 赠与 | V1.0 | ≥4
 | 粗销3*18（行星齿固定销） | 赠与 | V1.0 | ≥3
 | 粗销3*30（太阳齿固定销） | 赠与 | V1.0 | ≥1
 | 细销2*13（转子与减速箱同轴性） | 赠与 | V1.0 | ≥4
轴承 | 35*44*5（6707VV） | 标准件 | V1.0 | 1 | 大家不要相信tb，pdd等标注什么十几块进口轴承，像国际知名轴承，个人难买且不可能十几块几十块就能买到，直接上国产，哈轴什么的都行，一样的东西，但也别买太次的。后面的链接是主播用的，大家可以做个参考，未必非从这买。总共下来十多块钱，最大的那个轴承因为受力所以大家可以买稍微好一点的。 | 参考链接：：https://item.taobao.com/item.htm?id=566478619519
 | 20*27*4（6704ZZ） | 标准件 | V1.0 | 1
 | 12*18*4（6701ZZ） | 标准件 | V1.0 | 2
 | 3*9*5（603ZZ） | 标准件 | V1.0 | 4 |  | 参考链接：https://detail.tmall.com/item.htm?id=980707569008
 | 法兰4*7*2开式(旁置磁编用) | 标准件 | V1.0 | 1 |  | 参考链接：https://detail.tmall.com/item.htm?id=801235908709
无框力矩电机 | 海泰WK4310H(磁片版) | 零件适配的海泰 | V1.0 | 1 | 68元左右 | 官方店自行购买即可
径向磁铁 | 5*2mm磁编 | 5*2mm | V1.0 | 1 | 3元 | 淘宝搜索
大概购买链接一共7个 1.铨州拖进去6个或者7个 2.闲鱼打开我们店铺购买套件 3.轴承3个链接 4.电机一个链接 5.编码器磁铁 纯热爱纯分享，STEP因为适配铨州规则与公差，此版本有所取舍，大家可以根据自己想法改动，主播可以保证的是，直接用我们的，你肯定能用，但也仅仅是能用，望大家多一点包容，两位主播不靠这个挣钱，从0组装电机，我们互相学习一起进步就好，谢谢大家。

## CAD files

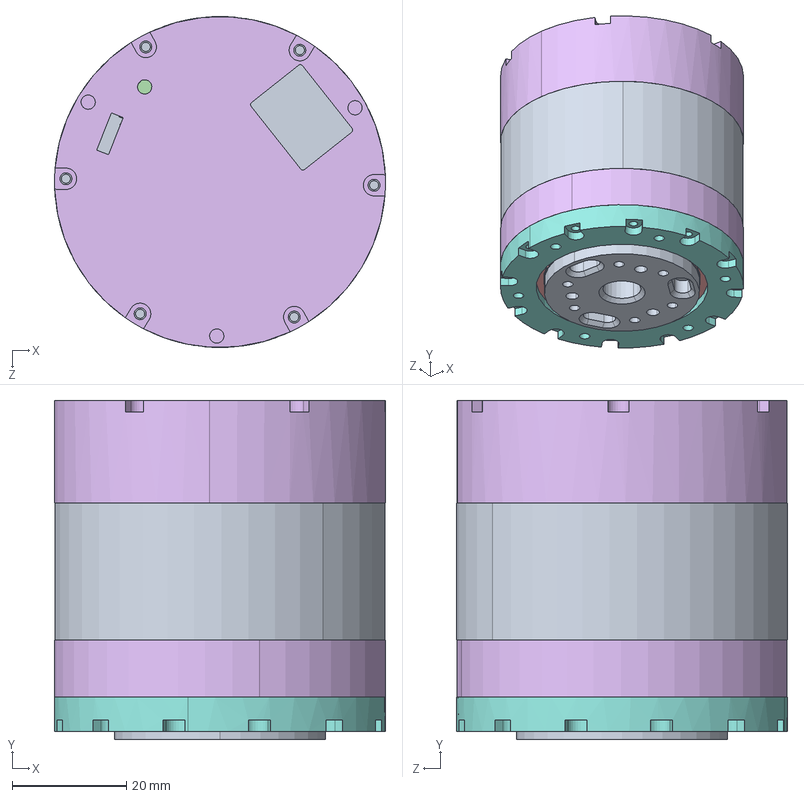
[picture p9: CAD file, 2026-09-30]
mechanical/asm/YHorizon-JM-asm.STEP
58.0 x 59.4 x 58.0 mm
50-行星保持架upperbase4.0
50-行星齿36z_0.5m x 3
50-3小轴承 x 3
50-行星保持架lower_base
50-35x44x5薄壁轴承
50-外齿圈支架
50-内齿圈84z_0.5m
4310________.STEP
WK4310____.STEP
WK4310________.STEP
PM4310____.STEP
50-20x27x4轴承
电机输出盘
50-12-16-4轴承 x 2
输出端盖
下端盖
磁编齿轮30×0.5
5-2磁铁 x 2
磁编齿轮31×0.5
磁编薄壁轴承
后壳

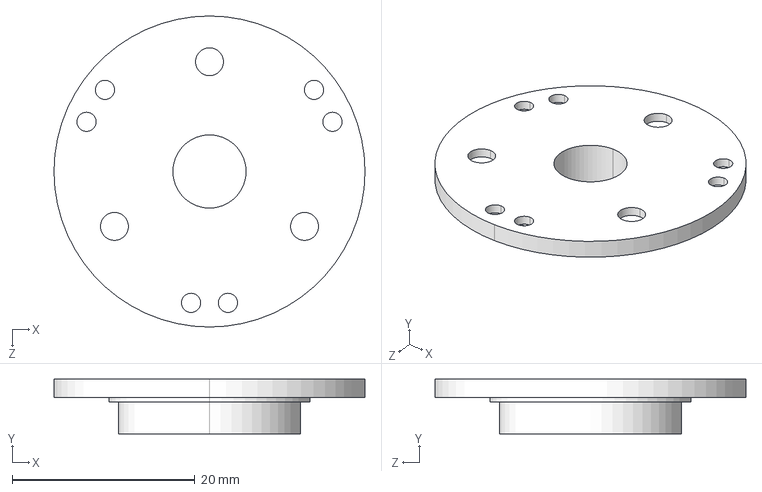
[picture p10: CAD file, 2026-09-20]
mechanical/cnc/行星保持架lower_base轴承公差版本.STEP
34.0 x 6.00 x 34.0 mm

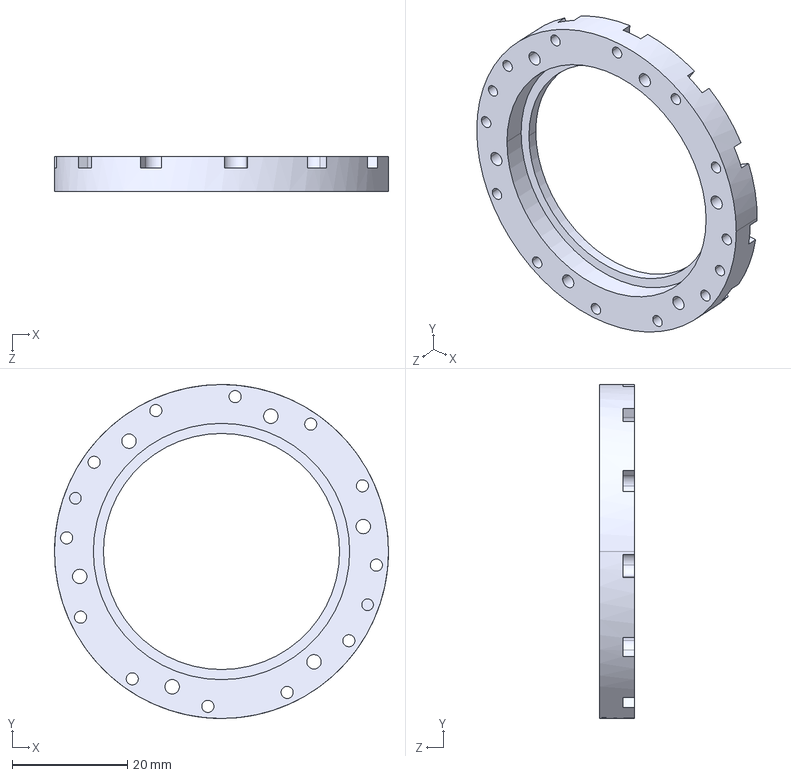
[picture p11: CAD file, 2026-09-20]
mechanical/cnc/输出端盖v1.0.STEP
58.0 x 58.0 x 6.00 mm

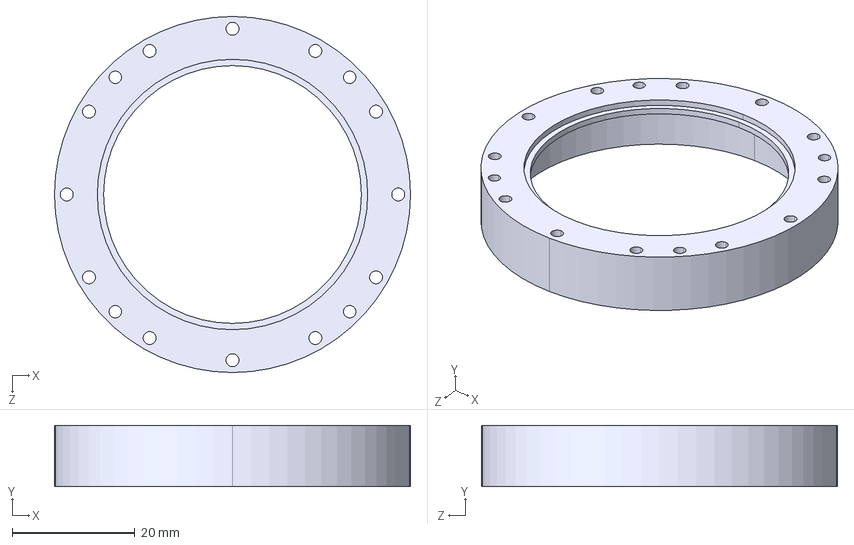
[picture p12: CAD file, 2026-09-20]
mechanical/cnc/50-外齿圈支架v1.0.STEP
58.0 x 10.0 x 58.0 mm

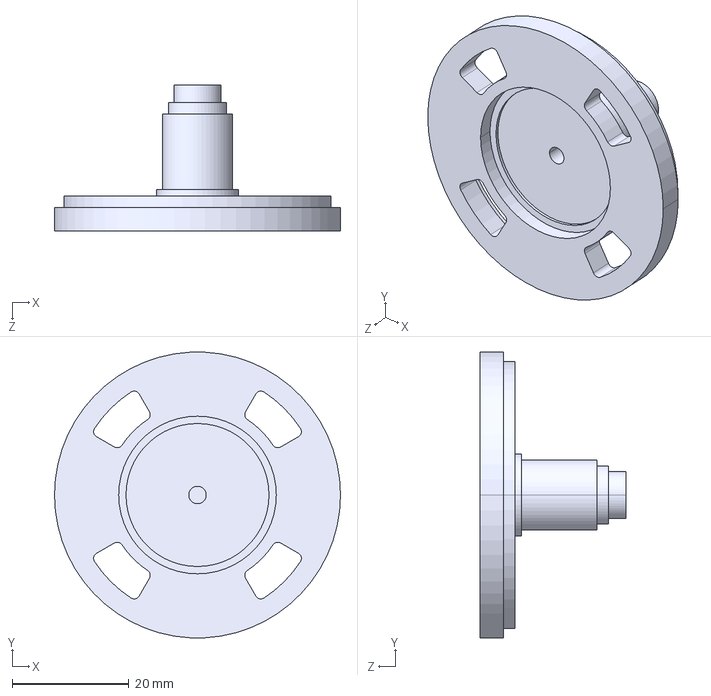
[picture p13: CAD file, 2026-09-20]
mechanical/cnc/电机输出盘v1.0.STEP
49.0 x 48.9 x 25.0 mm

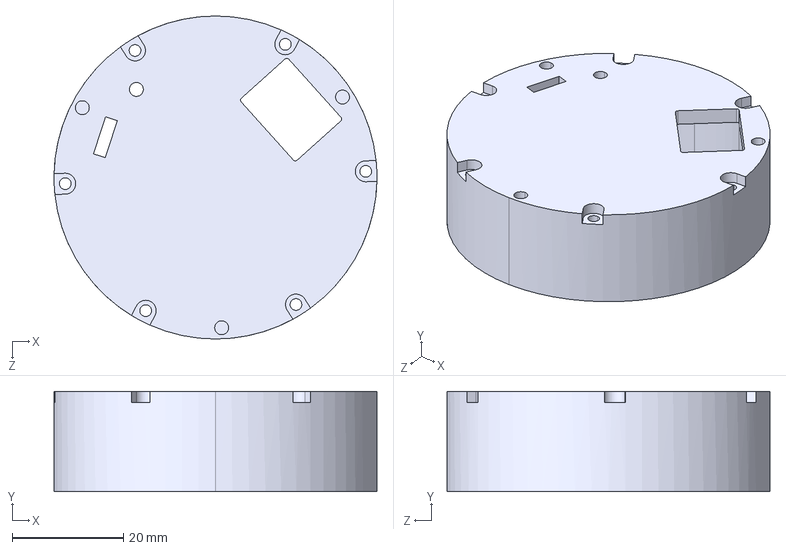
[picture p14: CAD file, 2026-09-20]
mechanical/cnc/后壳.STEP
58.0 x 18.0 x 58.0 mm

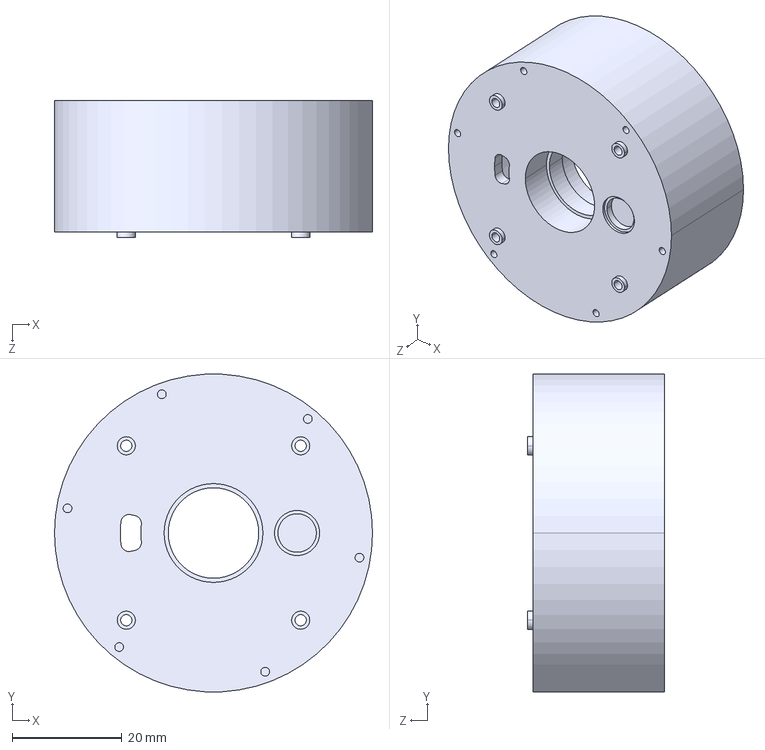
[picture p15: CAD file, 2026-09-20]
mechanical/cnc/下端盖v1.0.STEP
58.0 x 57.9 x 25.0 mm

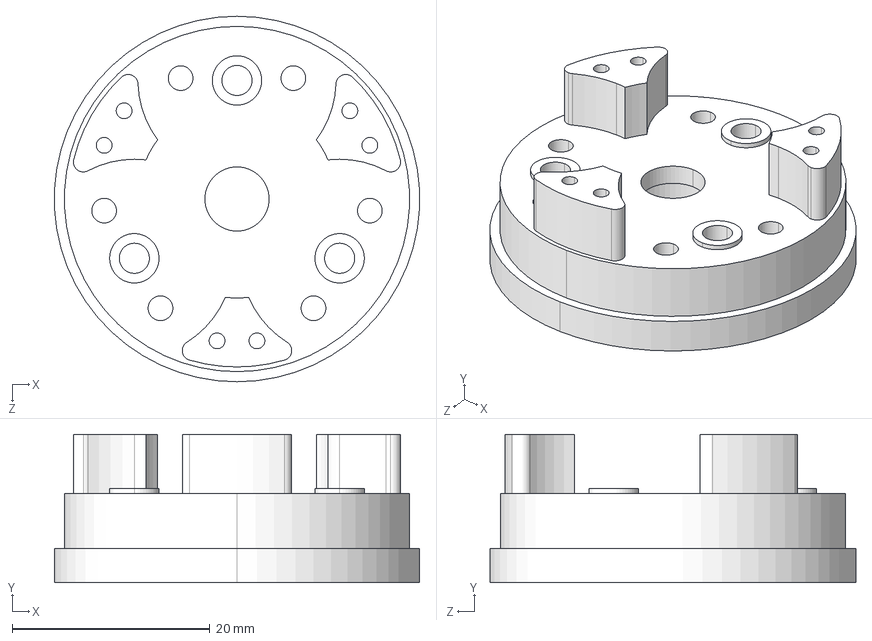
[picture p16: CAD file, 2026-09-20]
mechanical/cnc/行星保持架upperbase4.0轴承公差版本.STEP
36.9 x 15.0 x 37.0 mm

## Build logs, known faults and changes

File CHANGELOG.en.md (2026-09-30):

# Changelog

[中文](CHANGELOG.md) | [English](CHANGELOG.en.md)

## [Unreleased]

- Published EasyEDA Pro source and assembly STEP; commercial use remains prohibited

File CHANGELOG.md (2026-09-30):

# 变更记录

[中文](CHANGELOG.md) | [English](CHANGELOG.en.md)

## [Unreleased]

- 公开嘉立创 EDA Pro 源工程与装配体 STEP；仍禁止商用

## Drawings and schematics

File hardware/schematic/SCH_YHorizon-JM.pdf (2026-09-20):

# SMF48AVM

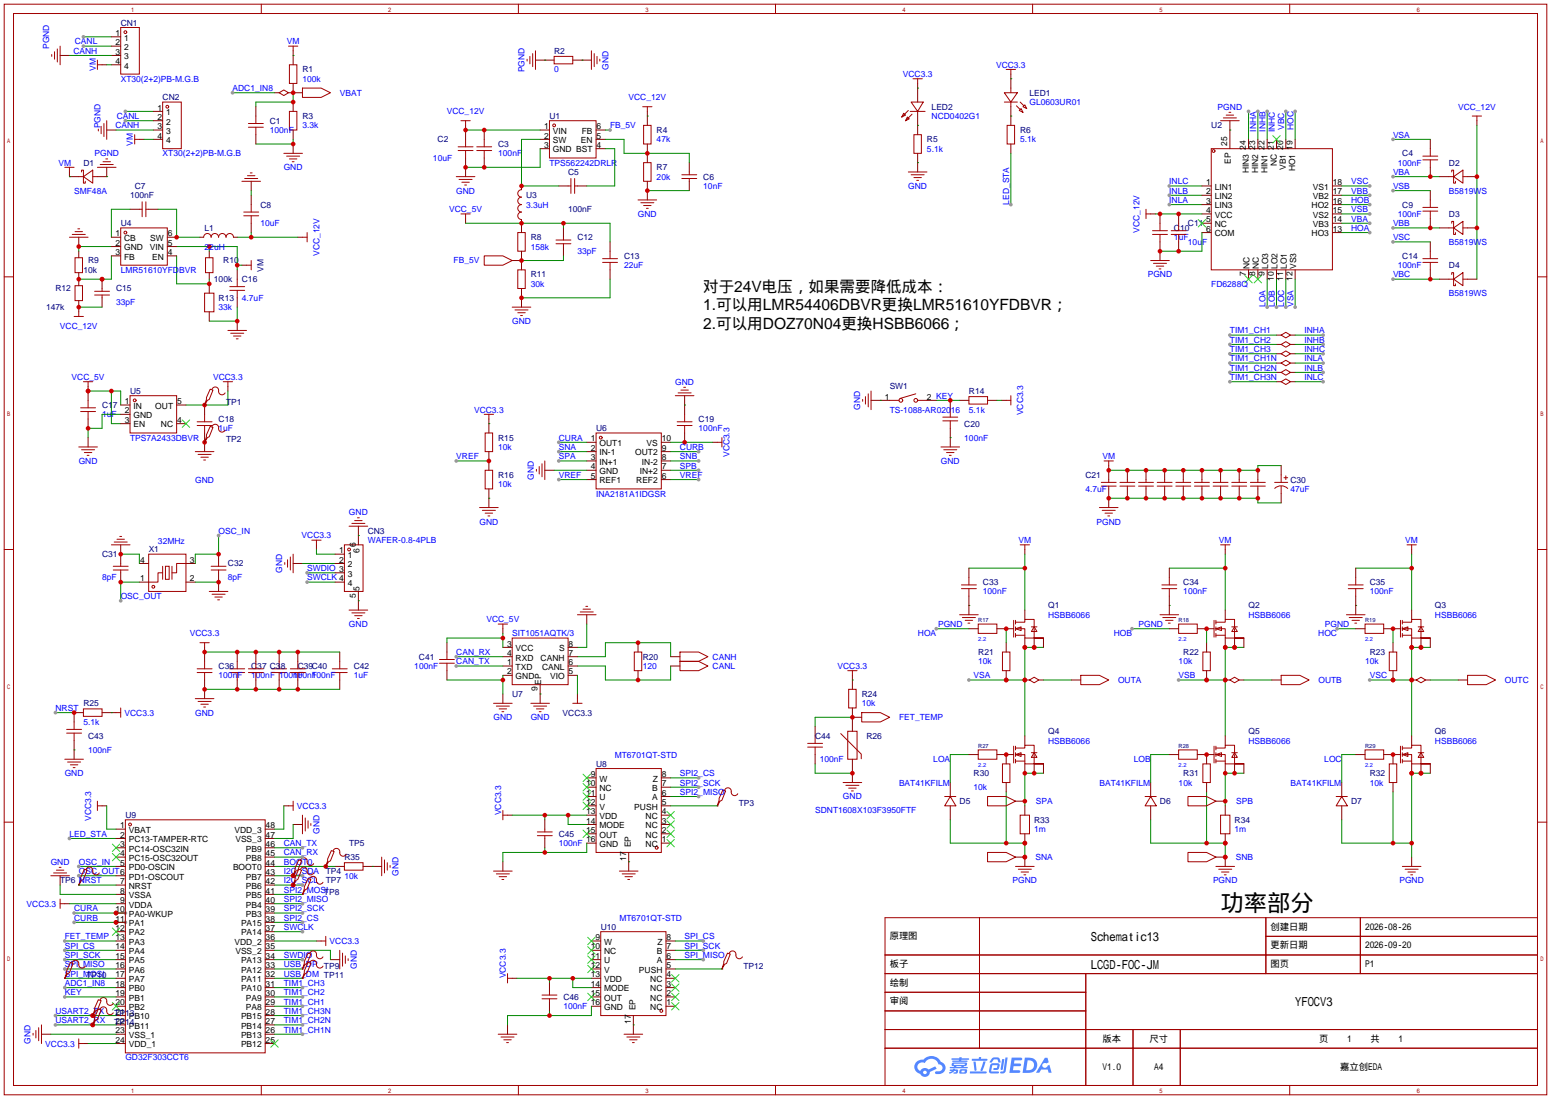
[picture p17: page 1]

原理图 | Schematic13 | 创建日期 | 2026-08-26

更新日期 | 2026-09-20

板子 | LCGD-FOC-JM | 图页 | P1

绘制 | | YFOCV3
审阅

V1.0 | A4 | 嘉立创EDA

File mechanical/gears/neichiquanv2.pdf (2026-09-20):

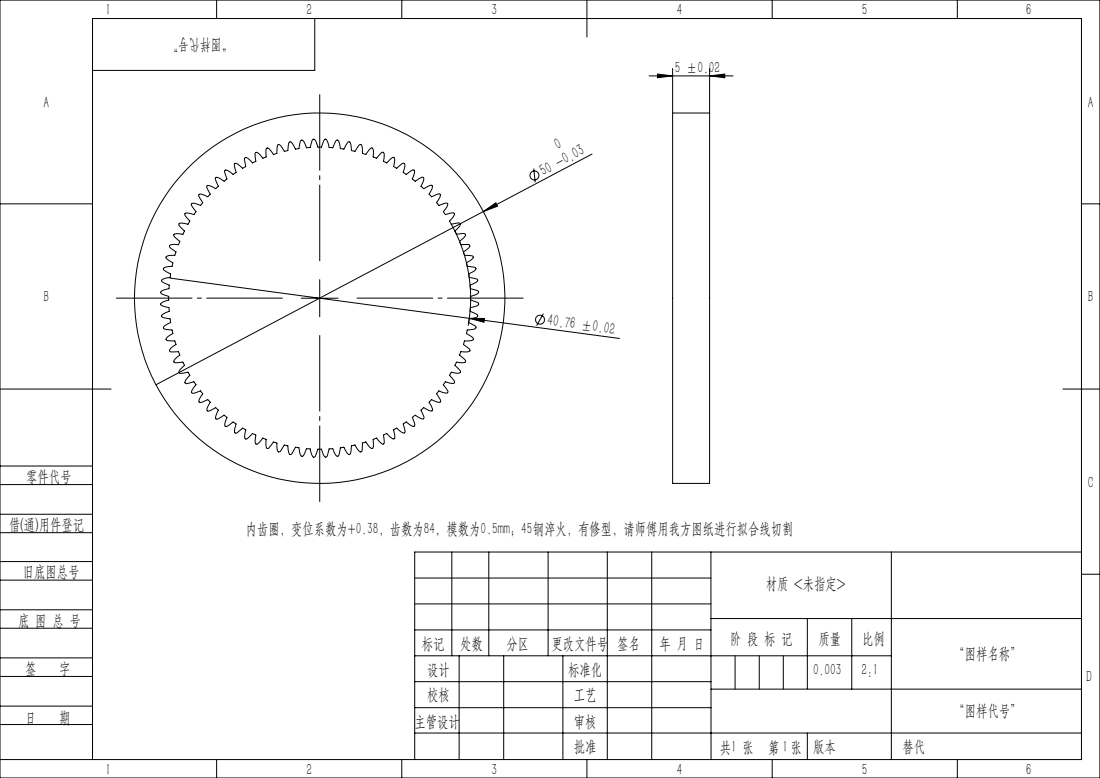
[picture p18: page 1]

内齿圈，变位系数为+0.38，齿数为84，模数为0.5mm；45钢淬火，有修型，请师傅用我方图纸进行拟合线切割

材质 <未指定>

阶 段 标 记 | 质量 | 比例 | “图样名称”

标记 | 处数 | 分区 | 更改文件号 | 签名 | 年 月 日

“图样代号”

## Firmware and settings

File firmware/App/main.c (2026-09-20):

#include "adc.h"
#include "board.h"
#include "cali.h"
#include "can.h"
#include "comm.h"
#include "config.h"
#include "debug.h"
#include "encoder.h"
#include "node.h"
#include "pwm.h"
#include "servo.h"

int main(void)
{
  uint32_t last_dbg_ms = 0U;
  uint8_t cali_ok;

  Board_Init();
  Dbg_Init();
  Encoder_Init();
  Servo_Init();
  Node_Init();
  Can_Init(Node_GetId());

  Dbg_Printf("YHorizon-JM GD32F303 voltage servo\r\n");
  Pwm_StartTimer();
  Board_LedSet(1U);
  cali_ok = Cali_Start();
  Comm_Init(cali_ok);
  if (cali_ok == 0U)
  {
    Dbg_Printf("cali failed\r\n");
  }
  else
  {
    Dbg_Printf("run\r\n");
  }

  for (;;)
  {
    uint32_t now;

    Can_Service();
    Adc_Service();
    Comm_Process();
    Node_Service(cali_ok);

    now = HAL_GetTick();
    if ((now - last_dbg_ms) >= CFG_DEBUG_PERIOD_MS)
    {
      ServoTelemetry_t tel;
      last_dbg_ms = now;
      Servo_GetTelemetry(&tel);
      Dbg_Printf("m=%d il=%d p=%d v=%d t=%d iq=%d vbus=%d\r\n",
                 (int)tel.ctrl_mode,
                 (int)tel.inner_loop,
                 (int)(tel.p_act * 1000.0f),
                 (int)(tel.v_act * 1000.0f),
                 (int)(tel.t_ref * 1000.0f),
                 (int)(tel.iq * 100.0f),
                 (int)(Adc_GetVbusVolts() * 100.0f));
    }
  }
}

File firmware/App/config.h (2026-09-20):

#ifndef YHJM_CONFIG_H
#define YHJM_CONFIG_H

#ifdef __cplusplus
extern "C" {
#endif

#define CFG_NODE_ID                 (1U)
#define CFG_NODE_ID_MIN             (1U)
#define CFG_NODE_ID_MAX             (63U)
#define CFG_POLE_PAIRS              (14U)

/**
 * @name Motor electrical (WK4310)
 * @brief Datasheet line-to-line R/L, halved to star phase for the current PI.
 *        Set @ref CFG_VBUS_NOMINAL_V to 24 or 48; PI also tracks measured Vbus.
 */
/** @{ */
#define CFG_MOTOR_R_LL_OHM          (10.32f)
#define CFG_MOTOR_L_LL_H            (4.76e-3f)
#define CFG_MOTOR_R_OHM             (CFG_MOTOR_R_LL_OHM * 0.5f)
#define CFG_MOTOR_L_H               (CFG_MOTOR_L_LL_H * 0.5f)
#define CFG_VBUS_NOMINAL_V          (24.0f)   /* 48.0f if 48 V pack */
#define CFG_VBUS_GAIN_MIN_V         (8.0f)
/** @} */

#define CFG_ENCODER_MT6701          (0U)
#define CFG_ENCODER_KTH7812         (1U)
#define CFG_ENCODER_TYPE            CFG_ENCODER_MT6701

/**
 * @name Vernier dual encoder
 * @brief Motor-end 30T + aux 31T recover 31 unique motor turns; output = motor / 8.
 */
/** @{ */
#define CFG_VERNIER_TEETH1          (30U)
#define CFG_VERNIER_TEETH2          (31U)
#define CFG_ENC2_DIR                (1)
#define CFG_ENC2_OFFSET_RAD         (0.0f)
#define CFG_GEAR_RATIO              (8.0f)
#define CFG_GEAR_RATIO_INV          (0.125f)
#define CFG_MULTI_TURN_ZERO_RAD     (0.0f)
/** @} */

#define CFG_HXTAL_HZ                (32000000UL)
#define CFG_SYSCLK_HZ               (112000000UL) /* HXTAL 32 MHz / 2 * 7 */
#define CFG_PWM_HZ                  (20000UL)
#define CFG_CTRL_HZ                 (4000UL)
#define CFG_PWM_DT_S                (1.0f / (float)CFG_PWM_HZ)
#define CFG_CTRL_DT_S               (1.0f / (float)CFG_CTRL_HZ)

#define CFG_TIM1_ARR                ((uint32_t)((CFG_SYSCLK_HZ / (2UL * CFG_PWM_HZ)) - 1UL))
#define CFG_TIM1_DEADTIME_DTG       (11U)   /* ~98 ns at 112 MHz, CKD=1 */
#define CFG_CTRL_TIM_PSC            ((CFG_SYSCLK_HZ / (CFG_CTRL_HZ * 250UL)) - 1UL)
#define CFG_CTRL_TIM_ARR            (249U)

#define CFG_V_LIMIT                 (0.50f)    /* pu; also clamps cali Vd/Vq */
#define CFG_V_SLEW_PU_S             (100.0f)   /* max |d(Vd,Vq)/dt|, pu/s */
#define CFG_VEL_LPF_HZ              (500.0f)  /* 2nd-order Butterworth on d(theta_e)/dt */

/**
 * @name Inner loop
 * @brief Outer motion/vel/pos always compute t_ref. Voltage: t_ref is Vq.
 *        Current: t_ref is mapped to Iq_ref, Id/Iq PI outputs Vd/Vq.
 *        Sampling always runs; default control stays voltage.
 */
/** @{ */
#define CFG_INNER_LOOP_VOLTAGE      (0U)
#define CFG_INNER_LOOP_CURRENT      (1U)
#define CFG_INNER_LOOP              CFG_INNER_LOOP_VOLTAGE
#define CFG_SHUNT_OHM               (0.001f)
#define CFG_CSA_GAIN                (20.0f)
#define CFG_I_LIMIT_A               (5.0f)  
#define CFG_CUR_BW_HZ               (500.0f)
#define CFG_ADC_I_TRIG_TICKS        (224U)     /* ~2 us after valley at 112 MHz */
#define CFG_ADC_I_OFFSET_SAMPLES    (32U)
/** @} */

#define CFG_ADC_VREF_V              (3.3f)
#define CFG_ADC_FULLSCALE           (4095.0f)
#define CFG_VBUS_SCALE              (31.303f) /* R1=100k / R3=3.3k: Vbus = Vadc * (100+3.3)/3.3 */
#define CFG_VBUS_LSB                (0.01f)
#define CFG_VBUS_POLL_MS            (5U)

#define CFG_CAN_MOTION_BASE         (0x100U)
#define CFG_CAN_VEL_BASE            (0x140U)
#define CFG_CAN_GAINS_BASE          (0x180U)
#define CFG_CAN_POS_BASE            (0x1C0U)
#define CFG_CAN_MGMT_BASE           (0x200U)
#define CFG_CAN_ACK_BASE            (0x280U)
#define CFG_CAN_FB_BASE             (0x300U)
#define CFG_CAN_STATUS_BASE         (0x380U)
#define CFG_CAN_CALI_RPT_BASE       (0x3C0U)
#define CFG_CAN_RX_SLOTS            (16U)

#define CFG_POS_LSB                 (0.0001f)
#define CFG_VEL_LSB                 (0.1f)
#define CFG_KP_LSB                  (0.01f)
#define CFG_KD_LSB                  (0.001f)
#define CFG_KP_VEL_LSB              (0.001f)
#define CFG_KI_VEL_LSB              (0.001f)
#define CFG_KP_POS_LSB              (0.01f)
#define CFG_KI_POS_LSB              (0.001f)
#define CFG_KD_POS_LSB              (0.001f)
#define CFG_TORQUE_LSB              (0.001f)
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

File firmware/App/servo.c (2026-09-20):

#include "servo.h"

#include "adc.h"
#include "config.h"
#include "encoder.h"
#include "foc_current.h"
#include "foc_math.h"
#include "foc_svpwm.h"
#include "foc_vernier.h"
#include "pwm.h"
#include "board.h"

#include <math.h>

static Foc_Encoder_t s_enc;
static Foc_Current_t s_cur;
static volatile ServoMode_t s_mode = SERVO_IDLE;
static volatile uint8_t s_ctrl_mode = SERVO_CTRL_MOTION;
static volatile uint8_t s_inner_loop = CFG_INNER_LOOP;
static volatile uint8_t s_cmd_valid = 0U;

static volatile float s_p_set;
static volatile float s_v_set;
static volatile float s_v_max;
static volatile float s_kp;
static volatile float s_kd;
static volatile float s_t_ff;
static volatile float s_t_ref;
static volatile float s_vel_kp;
static volatile float s_vel_ki;
static volatile float s_pos_kp;
static volatile float s_pos_ki;
static volatile float s_pos_kd;
static volatile int8_t s_closed_loop_dir = 1;

static float s_vel_i;
static float s_pos_i;

static volatile float s_ol_d;
static volatile float s_ol_q;
static volatile float s_ol_rate;
static volatile float s_ol_elec;

static volatile float s_volt_d;
static volatile float s_volt_q;
static float s_d_out;
static float s_q_out;
static volatile uint16_t s_enc1_raw;
static volatile uint8_t s_enc1_ok;
static float s_ia;
static float s_ib;

static void Servo_ClearLoopState(void)
{
  s_vel_i = 0.0f;
  s_pos_i = 0.0f;
  s_t_ref = 0.0f;
  s_cmd_valid = 0U;
}

static float Servo_PiLimited(float *i, float err, float kp, float ki, float dt, float lim)
{
  *i += ki * err * dt;
  *i = Foc_Clamp(*i, -lim, lim);
  return Foc_Clamp((kp * err) + *i, -lim, lim);
}

static float Servo_PosSpeedLimit(float ep, float vmax, float acc)
{
  float lim = vmax;

  if ((acc > 0.0f) && (lim > 0.0f))
  {
    const float v_dec = sqrtf(2.0f * acc * fabsf(ep));
    if (v_dec < lim)
    {
      lim = v_dec;
    }
  }
  return lim;
}

static float Servo_Slew(float current, float target, float max_step)
{
  const float delta = target - current;

  if (delta > max_step)
  {
    return current + max_step;
  }
  if (delta < -max_step)
  {
    return current - max_step;
  }
  return target;
}

static float Servo_MotorToOut(float motor_rad)
{
  return motor_rad * CFG_GEAR_RATIO_INV;
}

static void Servo_SyncVernier(void)
{
  uint16_t raw2;
  float raw_abs;
  float aligned_abs;

  if ((s_enc1_ok == 0U) || (Encoder2_ReadRawFast(&raw2) == 0U))
  {
    return;
  }
  if (Foc_VernierRawAbs(s_enc1_raw, raw2, &raw_abs) == 0U)
  {
    return;
  }
  aligned_abs = Foc_VernierAlignAbs(raw_abs, s_enc.direction);
  Foc_EncoderSyncAbs(&s_enc, aligned_abs, (float)FOC_VERNIER_MOTOR_TURNS * FOC_TWO_PI);
}

static void Servo_ApplyDq(float d_v, float q_v, float elec, uint8_t slew)
{
  Foc_Dq_t dq;
  Foc_AlphaBeta_t ab;
  float duty_a;
  float duty_b;
  float duty_c;

  dq.d = d_v;
  dq.q = q_v;
  Foc_LimitDQ(CFG_V_LIMIT, &dq.d, &dq.q);
  if (slew != 0U)
  {
    const float max_step = CFG_V_SLEW_PU_S * CFG_PWM_DT_S;
    s_d_out = Servo_Slew(s_d_out, dq.d, max_step);
    s_q_out = Servo_Slew(s_q_out, dq.q, max_step);
  }
  else
  {
    s_d_out = dq.d;
    s_q_out = dq.q;
  }
  dq.d = s_d_out;
  dq.q = s_q_out;
  ab = Foc_InversePark(dq, elec);
  Foc_SvpwmOffsetOptimized(ab.alpha, ab.beta, &duty_a, &duty_b, &duty_c);
  Pwm_ApplyDuty(duty_a, duty_b, duty_c);
}

void Servo_Init(void)
{
  Foc_EncoderConfig_t cfg;

  Foc_MathInit();
  cfg.pole_pairs = (uint8_t)CFG_POLE_PAIRS;
  cfg.direction = 1;
  cfg.electrical_offset_rad = 0.0f;
  cfg.vel_lpf_hz = CFG_VEL_LPF_HZ;
  cfg.sample_hz = (float)CFG_PWM_HZ;

  Foc_EncoderInit(&s_enc, &cfg);
  Foc_CurrentInit(&s_cur, CFG_MOTOR_R_OHM, CFG_MOTOR_L_H, CFG_CUR_BW_HZ,
                  CFG_VBUS_NOMINAL_V, CFG_I_LIMIT_A, CFG_V_LIMIT);
  s_mode = SERVO_IDLE;
  s_ctrl_mode = SERVO_CTRL_MOTION;
  s_inner_loop = CFG_INNER_LOOP;
  s_closed_loop_dir = 1;
  s_p_set = 0.0f;
  s_v_set = 0.0f;
  s_v_max = CFG_POS_VMAX_DEFAULT;
  s_kp = 0.0f;
  s_kd = 0.0f;
  s_t_ff = 0.0f;
  s_t_ref = 0.0f;
  s_vel_kp = Foc_Clamp(CFG_VEL_KP_DEFAULT, 0.0f, CFG_KP_VEL_MAX);
  s_vel_ki = Foc_Clamp(CFG_VEL_KI_DEFAULT, 0.0f, CFG_KI_VEL_MAX);
  s_pos_kp = Foc_Clamp(CFG_POS_KP_DEFAULT, 0.0f, CFG_KP_POS_MAX);
  s_pos_ki = Foc_Clamp(CFG_POS_KI_DEFAULT, 0.0f, CFG_KI_POS_MAX);
  s_pos_kd = Foc_Clamp(CFG_POS_KD_DEFAULT, 0.0f, CFG_KD_POS_MAX);
  s_vel_i = 0.0f;
  s_pos_i = 0.0f;
  s_cmd_valid = 0U;
  s_d_out = 0.0f;
  s_q_out = 0.0f;
  s_ia = 0.0f;
  s_ib = 0.0f;
}

static void Servo_ApplyEncoderSample(uint8_t ok, uint16_t raw)
{
  if (ok != 0U)
  {
    const float mech = ((float)raw * FOC_TWO_PI) / (float)ENCODER_CPR;
    (void)Foc_EncoderUpdate(&s_enc, mech, CFG_PWM_DT_S);
  }
  else
  {
    Foc_EncoderPredict(&s_enc, CFG_PWM_DT_S);
  }
}

static void Servo_UpdateCurrent(float elec, uint8_t run_pi, float id_ref, float iq_ref)
{
  float ia;
  float ib;

  if (Adc_ReadPhaseCurrents(&ia, &ib) != 0U)
  {
    s_ia = ia;
    s_ib = ib;
  }
  Foc_CurrentStep(&s_cur, s_ia, s_ib, elec, id_ref, iq_ref, CFG_PWM_DT_S, run_pi);
}

void Servo_OnPwmIsr(void)
{
  uint16_t raw;
  uint8_t ok;
  ServoMode_t mode = s_mode;
  float elec;

  ok = Encoder_ReadRawFast(&raw);
  s_enc1_ok = ok;
  if (ok != 0U)
  {
    s_enc1_raw = raw;
  }
  Servo_ApplyEncoderSample(ok, raw);

  if (mode == SERVO_OPENLOOP)
  {
    s_ol_elec = Foc_WrapAngle0To2Pi(s_ol_elec + (s_ol_rate * CFG_PWM_DT_S));
    elec = s_ol_elec;
    Servo_UpdateCurrent(elec, 0U, 0.0f, 0.0f);
    Servo_ApplyDq(s_ol_d, s_ol_q, elec, 1U);
  }
  else if (mode == SERVO_VOLTAGE)
  {
    elec = Foc_EncoderGetElectrical(&s_enc);
    Servo_UpdateCurrent(elec, 0U, 0.0f, 0.0f);
    Servo_ApplyDq(s_volt_d, s_volt_q, elec, 1U);
  }
  else if (mode == SERVO_RUN)
  {
    const float signed_ref = (float)s_closed_loop_dir * s_t_ref;
    elec = Foc_EncoderGetElectrical(&s_enc);
    if (s_inner_loop == CFG_INNER_LOOP_CURRENT)
    {
      const float iq_ref = signed_ref * (CFG_I_LIMIT_A / CFG_V_LIMIT);
      Servo_UpdateCurrent(elec, 1U, 0.0f, iq_ref);
      Servo_ApplyDq(s_cur.vd, s_cur.vq, elec, 0U);
    }
    else
    {
      Servo_UpdateCurrent(elec, 0U, 0.0f, 0.0f);
      Servo_ApplyDq(0.0f, signed_ref, elec, 1U);
    }
  }
  else
  {
    Servo_UpdateCurrent(Foc_EncoderGetElectrical(&s_enc), 0U, 0.0f, 0.0f);
  }
}
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

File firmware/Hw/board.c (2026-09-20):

#include "board.h"
#include "adc.h"
#include "config.h"

static volatile uint32_t s_tick_ms;

static void Board_GpioInit(void)
{
  rcu_periph_clock_enable(RCU_GPIOA);
  rcu_periph_clock_enable(RCU_GPIOB);
  rcu_periph_clock_enable(RCU_GPIOC);
  rcu_periph_clock_enable(RCU_AF);

  /* Free PA15 / PB3 / PB4 for SPI2; keep SWD on PA13/PA14. */
  gpio_pin_remap_config(GPIO_SWJ_SWDPENABLE_REMAP, ENABLE);

  /* LED_STA: PC13 sinks LED1 (active low). Idle high = off. */
  gpio_bit_set(GPIOC, GPIO_PIN_13);
  gpio_init(GPIOC, GPIO_MODE_OUT_PP, GPIO_OSPEED_50MHZ, GPIO_PIN_13);

  gpio_bit_set(GPIOA, GPIO_PIN_4 | GPIO_PIN_15);
  gpio_init(GPIOA, GPIO_MODE_OUT_PP, GPIO_OSPEED_50MHZ, GPIO_PIN_4 | GPIO_PIN_15);

  /* KEY on PB1, external 5.1 kΩ pull-up, pressed to GND. */
  gpio_init(GPIOB, GPIO_MODE_IPU, GPIO_OSPEED_50MHZ, GPIO_PIN_1);
}

static void Board_SpiFillCommon(spi_parameter_struct *spi_init_struct)
{
  spi_struct_para_init(spi_init_struct);
  spi_init_struct->trans_mode = SPI_TRANSMODE_FULLDUPLEX;
  spi_init_struct->device_mode = SPI_MASTER;
  spi_init_struct->nss = SPI_NSS_SOFT;
  spi_init_struct->endian = SPI_ENDIAN_MSB;
#if (CFG_ENCODER_TYPE == CFG_ENCODER_KTH7812)
  spi_init_struct->frame_size = SPI_FRAMESIZE_16BIT;
  spi_init_struct->clock_polarity_phase = SPI_CK_PL_HIGH_PH_2EDGE;
#else
  spi_init_struct->frame_size = SPI_FRAMESIZE_8BIT;
  spi_init_struct->clock_polarity_phase = SPI_CK_PL_LOW_PH_2EDGE;
#endif
}

static void Board_SpiInit(void)
{
  spi_parameter_struct spi_init_struct;

  rcu_periph_clock_enable(RCU_GPIOA);
  rcu_periph_clock_enable(RCU_GPIOB);
  rcu_periph_clock_enable(RCU_AF);
  rcu_periph_clock_enable(RCU_SPI0);
  rcu_periph_clock_enable(RCU_SPI2);

  gpio_init(GPIOA, GPIO_MODE_AF_PP, GPIO_OSPEED_50MHZ, GPIO_PIN_5 | GPIO_PIN_7);
  gpio_init(GPIOB, GPIO_MODE_AF_PP, GPIO_OSPEED_50MHZ, GPIO_PIN_3 | GPIO_PIN_5);
#if (CFG_ENCODER_TYPE == CFG_ENCODER_KTH7812)
  gpio_init(GPIOA, GPIO_MODE_IPU, GPIO_OSPEED_50MHZ, GPIO_PIN_6);
  gpio_init(GPIOB, GPIO_MODE_IPU, GPIO_OSPEED_50MHZ, GPIO_PIN_4);
#else
  gpio_init(GPIOA, GPIO_MODE_IN_FLOATING, GPIO_OSPEED_50MHZ, GPIO_PIN_6);
  gpio_init(GPIOB, GPIO_MODE_IN_FLOATING, GPIO_OSPEED_50MHZ, GPIO_PIN_4);
#endif

  Board_SpiFillCommon(&spi_init_struct);
#if (CFG_ENCODER_TYPE == CFG_ENCODER_KTH7812)
  spi_init_struct.prescale = SPI_PSC_16; /* APB2 112 MHz / 16 = 7 MHz */
#else
  spi_init_struct.prescale = SPI_PSC_8;  /* APB2 112 MHz / 8 = 14 MHz */
#endif
  spi_i2s_deinit(SPI0);
  spi_init(SPI0, &spi_init_struct);
  spi_enable(SPI0);

  Board_SpiFillCommon(&spi_init_struct);
#if (CFG_ENCODER_TYPE == CFG_ENCODER_KTH7812)
  spi_init_struct.prescale = SPI_PSC_8;  /* APB1 56 MHz / 8 = 7 MHz */
#else
  spi_init_struct.prescale = SPI_PSC_4;  /* APB1 56 MHz / 4 = 14 MHz */
#endif
  spi_i2s_deinit(SPI2);
  spi_init(SPI2, &spi_init_struct);
  spi_enable(SPI2);
}

static void Board_CanGpioInit(void)
{
  rcu_periph_clock_enable(RCU_GPIOB);
  rcu_periph_clock_enable(RCU_AF);
  rcu_periph_clock_enable(RCU_CAN0);

  /* Default CAN0 is PA11/PA12 (USB D-/D+). Partial remap → PB8/PB9. */
  gpio_pin_remap_config(GPIO_CAN_PARTIAL_REMAP, ENABLE);

  gpio_init(GPIOB, GPIO_MODE_IPU, GPIO_OSPEED_50MHZ, GPIO_PIN_8);
  gpio_init(GPIOB, GPIO_MODE_AF_PP, GPIO_OSPEED_50MHZ, GPIO_PIN_9);
}

static void Board_Tim0Init(void)
{
  timer_parameter_struct timer_initpara;
  timer_oc_parameter_struct timer_ocinitpara;
  timer_break_parameter_struct timer_breakpara;
  uint16_t pulse_50;

  rcu_periph_clock_enable(RCU_GPIOA);
  rcu_periph_clock_enable(RCU_GPIOB);
  rcu_periph_clock_enable(RCU_AF);
  rcu_periph_clock_enable(RCU_TIMER0);

  gpio_init(GPIOA, GPIO_MODE_AF_PP, GPIO_OSPEED_50MHZ,
            GPIO_PIN_8 | GPIO_PIN_9 | GPIO_PIN_10);
  gpio_init(GPIOB, GPIO_MODE_AF_PP, GPIO_OSPEED_50MHZ,
            GPIO_PIN_13 | GPIO_PIN_14 | GPIO_PIN_15);

  timer_deinit(TIMER0);
  timer_struct_para_init(&timer_initpara);
  timer_initpara.prescaler = 0U;
  timer_initpara.alignedmode = TIMER_COUNTER_CENTER_UP;
  timer_initpara.counterdirection = TIMER_COUNTER_UP;
  timer_initpara.period = (uint16_t)CFG_TIM1_ARR;
  timer_initpara.clockdivision = TIMER_CKDIV_DIV1;
  timer_initpara.repetitioncounter = 1U;
  timer_init(TIMER0, &timer_initpara);

  timer_channel_output_struct_para_init(&timer_ocinitpara);
  timer_ocinitpara.outputstate = TIMER_CCX_DISABLE;
  timer_ocinitpara.outputnstate = TIMER_CCXN_DISABLE;
  timer_ocinitpara.ocpolarity = TIMER_OC_POLARITY_HIGH;
  timer_ocinitpara.ocnpolarity = TIMER_OCN_POLARITY_HIGH;
  timer_ocinitpara.ocidlestate = TIMER_OC_IDLE_STATE_LOW;
  timer_ocinitpara.ocnidlestate = TIMER_OCN_IDLE_STATE_LOW;
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

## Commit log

2026-09-20 YHorizon-JM开源
    [50-外齿圈支架v1.0.STEP, BOM_YHorizon-JM.xlsx, 下端盖v1.0.STEP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]
2026-09-20 更新 README 文件，包含 CNC 订单备注和新图片；添加了关于 PCB 组和 V2 发布的信息。
2026-09-22 添加装配视频链接
2026-09-30 添加上了装配体STEP和PCB设计文件
    [YHorizon-JM-asm.STEP]
2026-11-03 更新说明
